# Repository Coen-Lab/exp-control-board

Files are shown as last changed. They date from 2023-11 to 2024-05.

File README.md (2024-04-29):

# Experimental Control Board (ECB)
This repository houses the electronics, firmware, and enclosure design for the experimental control board. This board was designed by [Max Hunter](https://maxhunter.me/), to the specifications of Philip Coen. It  is designed both with features that are universally applicable to experimental neuroscience rigs, as well as some features which may not (but may) be useful outside the Coen Lab. In particular, the assembled board can be purchased at a comparable price to a _single component_ from a commercial supplier (e.g. this [current driver](https://www.thorlabs.com/thorproduct.cfm?partnumber=LEDD1B) or this [adjustable photodiode](https://www.thorlabs.com/thorproduct.cfm?partnumber=PDA8A2)). For most applications, this board can fully replace these components (in the enclosure of the current driver, it can replace 3 of them), amongst others.

<p align="center">

</p>

If purchased directly from Max, the Version 3 board includes:
- 24V, 220W power supply
- Photodiode (2-pin)
- Temperature sensor (3-pin)
- Enclosure (Pink in above images)
- ECB Version 3 with the following features
	- Temperature-controlled PID Peltier cooler output with overheat protection
	- Two fixed 12V, 3A power rails for auxiliary devices, with switchable on/off outputs
	- Four variable 3-24V, 3A power rails for auxiliary devices, with switchable on/off outputs
	- Three adjustable 0-1A continuous current drivers for LEDs or similar devices
	- Photosensor with variable sensitivity trigger (5V TTL digital output)
	- Two DRV104 valve controllers, 12V output
	- One Arduino Nano V3, used to control Peltier output and random ‘flipper’ output, with 6 spare IO for future expansion

For useage instructions, please see:

[Version 3 documentation](Version3/README.md)

To purchase pre-assembled units, including photodiode etc. mentioned above, for ~£450 (at time of writing), please contact [Max Hunter](https://maxhunter.me/). 

All details are open source, and you can alternatively print your own boards: there is a folder of Gerbers and pick 'n place files for each version. However, please be aware that stock levels may necessitate equivalent-part subsitutions, so if you aren't familiar with ordering your own PCBs (e.g. you have no idea what Gerbers and pick 'n place files are), then we _strongly_ recommend you order pre-assembled units. Max may also be able to make minor design changes (for a design fee) if there are particular elements you would like added or removed.

&nbsp;
&nbsp;
This work is licensed under a
[Creative Commons Attribution-NonCommercial-ShareAlike 4.0 International License][cc-by-nc-sa].

[][cc-by-nc-sa]

[cc-by-nc-sa]: http://creativecommons.org/licenses/by-nc-sa/4.0/
[cc-by-nc-sa-image]: https://licensebuttons.net/l/by-nc-sa/4.0/88x31.png
[cc-by-nc-sa-shield]: https://img.shields.io/badge/License-CC%20BY--NC--SA%204.0-lightgrey.svg

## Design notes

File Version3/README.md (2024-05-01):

## ECB Version 3 guide and usage instructions
<p align="center">

</p>

_Above_: Version 3 board CAD file (left) with both top and bottom of enclosure (centre) or just the bottom of the enclosure (right)

Thanks for purchasing (or considering) the ECB Version 3! This guide should act as a basic how-to to get started. If you have any questions/issues please post them on this github so that the entire community can benefit from the answers.

A purchasable Bill of Materials, all source code for the Arduino, a 3D-printable enclosure, and electronics design files can be found in this repository.

The board comes with a one-year warranty against manufacturing defects.

If you have any further questions or have any problems, please leave an issue on this GitHub repository.

## General notes
If purchased directly from Max, you have received:

- 24V, 220W power supply
- Photodiode (2-pin)
- Temperature sensor (3-pin)
- ECB Version 3 with the following features
    - Temperature-controlled PID Peltier cooler output with overheat protection
    - Two fixed 12V, 3A power rails for auxiliary devices, with switchable on/off outputs
    - Four variable 3-24V, 3A power rails for auxiliary devices, with switchable on/off outputs
    - Three adjustable 0-1A continuous current drivers for LEDs or similar devices
    - Photosensor with variable sensitivity trigger (5V TTL digital output)
    - Two DRV104 valve controllers, 12V output
    - One Arduino Nano V3, used to control Peltier output and random ‘flipper’ output, with 6 spare IO for future expansion

Please take the following precautions when handling the board.

* **At no point should you “hot-plug” / screw or unscrew anything into the board when it is powered on. The rapid transients caused by the making/breaking of contacts when screwing a cable in can damage the board as well as any attached components.**
* Do not overload or short-circuit any of the power rails.
* Please pay attention to the total maximum power rating of 220W, which is possible to exceed if fully loading all voltage rails.
* When handling or touching any components on the board, you should ground yourself with an ESD bracelet (£4 on Amazon) or by touching any grounded surface to dissipate electrostatic charge. Humans can accumulate several thousand volts of static charge which will dissipate through the board: several of the components on the board are very sensitive to ESD. When screwing in any of the terminals, take the same precaution, or use an insulated screwdriver so your skin does not make contact with the screw of the terminal.

## Installation/operation instructions

### General notes on screw terminals
All the external connections to the board are made using screw terminals. These accept a wide variety of wire sizes. You should strip 5mm off the wire, then unscrew the terminal until the jaws fully open, insert the wire, and hand-tighten. The screw should clamp down on the conductor (not the insulation) and no conductor should be visible out the end of the connector.

For low-power devices with small cable sizes it is acceptable to insert several wires into a single terminal, as long as they are all sufficiently stripped so that they are making good contact with the terminal.

### Enclosure
Four self-tapping screws can be inserted into the four corners of the enclosure in the pre-drilled holes to mount onto any suitable surface. The board can be installed in any orientation but preferably should be kept away from direct sunlight and heat sources.

### Power in


The board comes with a switchmode 24V, 220W power supply. You should sum up all the power ratings of the various attached devices (including Peltier cooler) and make sure they do not exceed 220W.

Once in the correct position, the insulation on the power connector should be cut off and the ends stripped to 5mm. Slightly twist the copper to make sure no strands splay off, then insert BLACK into ⏚ and RED into +24.

### Power out


There are 6 power rails for auxiliary devices on this board. All of them share the same 3A current rating.

RAIL 1: 12V fixed

RAIL 2: 12V fixed

RAIL 3: Variable 3-23V

RAIL 4: Variable 3-23V

RAIL 5: Variable 3-23V

RAIL 6: Variable 3-23V

RAIL 3-6 are adjustable by turning the potentiometers (blue cuboids) next to the relevant rails with a small insulated flat screwdriver, whilst metering the output voltage with the serial logger on the Arduino, or a multimeter. Care should be taken to make sure the screwdriver does not slip and you do not touch any other components while metering, especially if using a multimeter.

All rails have a GATE input. Leaving this pin disconnected, or connecting this to a voltage below approximately 1.3 V, turns the regulator on, and pulling this pin above 1.3 V (up to a maximum of 25 V) shuts the regulator down. This is a useful feature if you wish to use an Arduino pin (or other logic pin) to switch power to an external component. (Note that there are output capacitors on the voltage rails so the power will not switch off instantly)

### Peltier


This board is tested and designed to work with the following 24V, 60W Peltier cooling module: [https://uk.rs-online.com/web/p/heat-pumps/7777079](https://uk.rs-online.com/web/p/heat-pumps/7777079). Other modules may work, as long as they are 24V and do not exceed 8A.

Insert BLACK into ⏚ and RED into PELT.

Connect overheat switch to any terminal marked ⏚ and OHT (polarity does not matter). This is a NC (normally closed) design which opens if the Peltier overheats - if your Peltier unit does not have an overheat sensor you should either modify the Arduino code or put a small bit of wire between OHT and ⏚ to bypass it.

The temperature sensor (mandatory for Peltier cooling) should be plugged into T SENSOR. Red into +5, yellow into D (data), black into ⏚. It should be positioned close to/underneath the desired position to be kept at a constant temperature.

The two fans (if available) should be plugged into any +12V rail.

The code for the Peltier follows a PID loop with a frequency of approximately 800KHz. It is roughly tuned for The Coen Lab’s original experimental box and so the P, I, D constants may need adjusting if the temperature proves to oscillate or under/overshoot in a new environment or with a different Peltier.

### Photodiode


This is a completely separate module from the rest of the board, designed as an adjustable photodiode trigger at a user-settable light threshold - originally designed to be placed next to a square on a screen to synchronise it with experimental data. This turns a variable light level into a digital 5V TTL logic output. There is a Schmitt trigger to remove hysteresis. The included photodiode (optional) should be plugged with the RED wire into S- and the BLUE wire into S+. The photodiode should be placed in the desired position and the potentiometer adjusted for the desired sensitivity.

The output between OUT and ⏚ is the 5V TTL out. The output between RAW and ⏚ is designed as an ‘analogue backup’ in case the sensitivity is slightly wrong - it is an analogue voltage (controlled by the SENSITIVITY  knob) before the Schmitt comparator where 2.5V is approximately the midpoint threshold.

### Valve drivers


These are 2 completely independent valve drivers. They take 5V TTL logic in (between IN and ⏚) and connect to a valve. The specs are fixed and as follows:

This was designed for the following valve:

225P011-21 ([https://www.nresearch.com/products/valves/pinch-1xnc.html](https://www.nresearch.com/products/valves/pinch-1xnc.html))

When the logic level input goes above approximately 2.2V (maximum 5.5V) the output briefly rises to 12V for 100ms, then continues to pulse between 0V and 12V at a 33% duty cycle until the input voltage drops beneath approximately 1.2V. This keeps the valve open without burning out the solenoid.

### Constant current drivers
\
\

There are 3 constant-current drivers on this board. They are adjustable in 3 fixed steps: 333mA, 667mA, 1000mA, by adding or removing jumpers on the board as shown.

They can also be controlled with the CTL pin for the relevant output as follows:

0-2.5V: scales linearly between 0A and the maximum set current (i.e. if the jumpers are set to 1A, setting the CTL pin at 1.25V will output a target current of 500mA).

2.5-5V: fully ON.

This can be used either as analogue control from 0-2.5V, or as a digital on/off switch by modulating the input voltage between 0 and 5V.

There is an internal pull-up resistor, so leaving this pin floating is the same as pulling it up to +5V (ie "on").

### Arduino I/O
\

This is a breakout board for the included Arduino Nano v3. 

The implemented features in the provided firmware are:

A ‘flipper’ random I/O which randomly flips between HIGH and LOW approximately every 100ms. This is turned on and off by setting FE (flipper enable) to HIGH or LOW.

An OHT overheat sensor for the Peltier (described in the Peltier section above)

Two ⏚ ground terminals and a 5V logic output. This 5V output is a logic reference only and not to be used for power. Drawing more than 50mA of current through it will result in permanent damage to the board. If there is any chance of it shorting to ground (or any other voltage), a 200 ohm resistor in series with it is strongly recommended.

The other outputs match the Arduino pinout and are reserved for future expansion.

Plugging the board into a computer is optional and only needed if you wish to log temperature/rail voltages etc, or update the firmware.

The firmware is available on GitHub and can be modified and uploaded using the connector on the Arduino. Plugging in the USB-C connector and opening up the serial logger on the Arduino app (or a MATLAB/Python program) will print rail voltages and temperature. You can then use the Arduino app to reflash any firmware changes.

## Manufacturing instructions

### Board

A service like JLCPCB can be used with the included Gerber and pick&place files to manufacture and assemble the board.

### Enclosure


Pip Coen has designed a 3D-printable enclosure which can be found in this repository.

The enclosure is designed to take 8 regular M4 nuts and M4 bolts.

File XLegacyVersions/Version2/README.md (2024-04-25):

## PipCB v2 assembly and usage instructions

### Max Hunter, March 2024

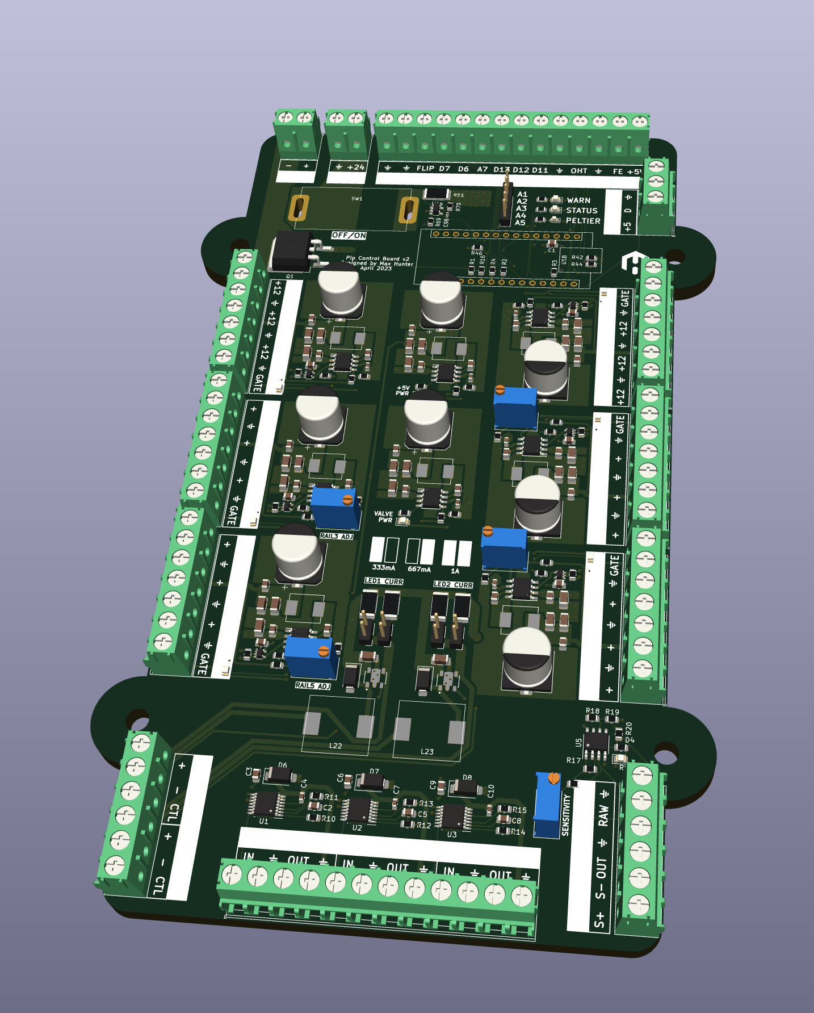
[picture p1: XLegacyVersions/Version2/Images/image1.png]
Overview


Thanks for purchasing a PipCB! This guide should act as a basic how-to to get started.

A purchasable Bill of Materials, all source code for the Arduino, and electronics design files can be found in this repository.

The board comes with a one-year warranty against manufacturing defects.

If you have any further questions or have any problems, please leave an issue on this GitHub repository.

## General notes

This board was designed by [Max Hunter](https://maxhunter.me/), to the specifications of Philip Coen. It  is designed both with features that are universally applicable to experimental neuroscience rigs, as well as some features which may not (but may) be useful outside the Coen Lab. In particular, the entire board costs less than the commercial equivalent of some single features (e.g. constant current delivery, or a thresholded, adjustable photodiode circuit).

The board as sold comprises:

- 24V, 220W power supply
- Photodiode (2-pin)
- Temperature sensor (3-pin)
- Enclosure
- ECB Version 2 with the following features
    - Temperature-controlled PID Peltier cooler output with overheat protection
    - Two fixed 12V, 3A power rails for auxiliary devices, with switchable on/off outputs
    - Four variable 3-24V, 3A power rails for auxiliary devices, with switchable on/off outputs
    - Two adjustable 0-1A continuous current drivers for LEDs or similar devices
    - Photosensor with variable sensitivity trigger (5V TTL digital output)
    - Three DRV104 valve controllers, 12V output
    - One Arduino Nano V3, used to control Peltier output and random ‘flipper’ output, with 6 spare IO for future expansion

Please take the following precautions when handling the board.

* **At no point should you “hot-plug” / screw or unscrew anything into the board when it is powered on. The rapid transients caused by the making/breaking of contacts when screwing a cable in can damage the board as well as any attached components.**
* Do not overload or short-circuit any of the power rails.
* Please pay attention to the total maximum current rating of 220W, which is possible to exceed if fully loading all voltage rails.
* When handling or touching any components on the board, you should ground yourself with an ESD bracelet (£4 on Amazon) or by touching any grounded surface to dissipate electrostatic charge. Humans can accumulate several thousand volts of static charge which will dissipate through the board: several of the components on the board are very sensitive to ESD. When screwing in any of the terminals, take the same precaution, or use an insulated screwdriver so your skin does not make contact with the screw of the terminal.

## Installation/operation instructions

### General notes on screw terminals

All the external connections to the board are made using screw terminals. These accept a wide variety of wire sizes. You should strip 5mm off the wire, then unscrew the terminal until the jaws fully open, insert the wire, and hand-tighten. The screw should clamp down on the conductor (not the insulation) and no conductor should be visible out the end of the connector.

For low-power devices with small cable sizes it is acceptable to insert several wires into a single terminal, as long as they are all sufficiently stripped so that they are making good contact with the terminal.

### Case

Four self-tapping screws can be inserted into the four corners of the case in the pre-drilled holes to mount onto any suitable surface. The board can be installed in any orientation but preferably should be kept away from direct sunlight and heat sources.

### Power in

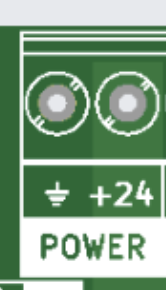
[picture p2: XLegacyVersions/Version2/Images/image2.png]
Power in Power input


The board comes with a switchmode 24V, 220W power supply. You should sum up all the current ratings of the various attached devices (including Peltier cooler) and make sure they do not exceed 220W.

Once in the correct position, the insulation on the power connector should be cut off and the ends stripped to 5mm. Slightly twist the copper to make sure no strands splay off, then insert BLACK into ⏚ and RED into +24.

### Power out

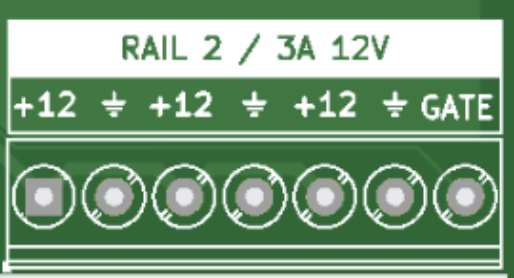
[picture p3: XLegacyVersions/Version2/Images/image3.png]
Power outputs


There are 6 power rails for auxiliary devices on this board. All of them share the same 3A current rating.

RAIL 1: 12V fixed

RAIL 2: 12V fixed

RAIL 3: Variable 3-23V

RAIL 4: Variable 3-23V

RAIL 5: Variable 3-23V

RAIL 6: Variable 3-23V

RAIL 3-6 are adjustable by turning the potentiometers next to the relevant rails with a small insulated flat screwdriver, whilst metering the output voltage with the serial logger on the Arduino, or a multimeter. Care should be taken to make sure the screwdriver does not slip and you do not touch any other components while metering, especially if using a multimeter.

All rails have a GATE input. Leaving this pin disconnected, or connecting this to a voltage below approximately 1.3 V, turns the regulator on, and pulling this pin above 1.3 V (up to a maximum of 25 V) shuts the regulator down. This is a useful feature if you wish to use an Arduino pin (or other logic pin) to switch power to an external component. (Note that there are output capacitors on the voltage rails so the power will not switch off instantly)

### Peltier

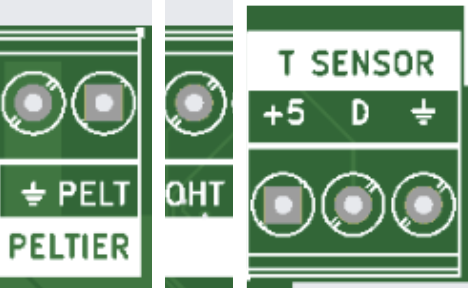
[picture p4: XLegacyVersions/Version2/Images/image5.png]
Peltier Peltier connectors


This board is tested and designed to work with the following 24V, 60W Peltier cooling module: [https://uk.rs-online.com/web/p/heat-pumps/7777079](https://uk.rs-online.com/web/p/heat-pumps/7777079). Other modules may work, as long as they are 24V and do not exceed 8A.

Insert BLACK into ⏚ and RED into PELT.

Connect overheat switch to any terminal marked ⏚ and OHT (polarity doesn’t matter). This is a NC (normally closed) design which opens if the Peltier overheats - if your Peltier unit does not have an overheat sensor you should either modify the Arduino code or put a small bit of wire between OHT and ⏚ to bypass it.

The temperature sensor (mandatory for Peltier cooling) should be plugged into T SENSOR. Red into +5, yellow into D (data), black into ⏚. It should be positioned close to/underneath the desired position to be kept at a constant temperature.

The two fans (if available) should be plugged into any +12V rail.

The code for the Peltier follows a PID loop with a frequency of approximately 800KHz. It is roughly tuned for Pip’s original experimental box and so the P, I, D constants may need adjusting if the temperature proves to oscillate or under/overshoot in a new environment or with a different Peltier.

### Photodiode

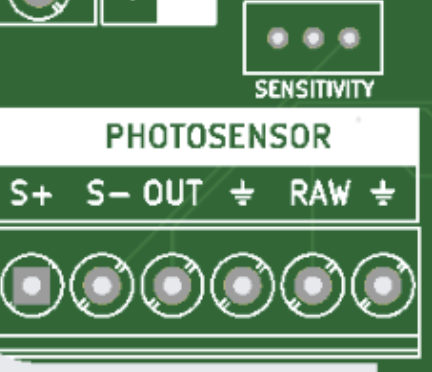
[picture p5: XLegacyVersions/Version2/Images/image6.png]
Photodiode Photodiode connectors


This is a completely separate module from the rest of the board, designed as an adjustable photodiode trigger at a user-settable light threshold - originally designed to be placed next to a square on a screen to synchronise it with experimental data. This turns a variable light level into a digital 5V TTL logic output. There is a Schmitt trigger to remove hysteresis. The included photodiode (optional) should be plugged with the RED wire into S- and the BLUE wire into S+. The photodiode should be placed in the desired position and the potentiometer adjusted for the desired sensitivity.

The output between OUT and ⏚ is the 5V TTL out. The output between RAW and ⏚ is designed as an ‘analogue backup’ in case the sensitivity is slightly wrong - it is an analogue voltage (controlled by the SENSITIVITY  knob) before the Schmitt comparator where 2.5V is approximately the midpoint threshold.

### Valve drivers

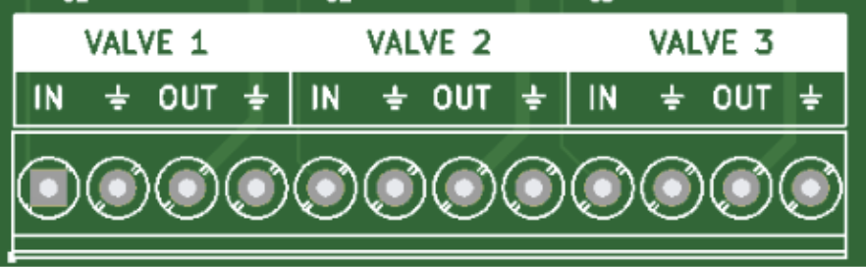
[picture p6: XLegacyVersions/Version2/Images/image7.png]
Valve drivers


These are 3 completely independent valve drivers. They take 5V TTL logic in (between IN and ⏚) and connect to a valve. The specs are fixed and as follows:

This was designed for the following valve:

225P011-21 ([https://www.nresearch.com/products/valves/pinch-1xnc.html](https://www.nresearch.com/products/valves/pinch-1xnc.html))

When the logic level input goes above approximately 2.2V (maximum 5.5V) the output briefly rises to 12V for 100ms, then continues to pulse between 0V and 12V at a 33% duty cycle until the input voltage drops beneath approximately 1.2V. This keeps the valve open without burning out the solenoid.

### Constant current drivers

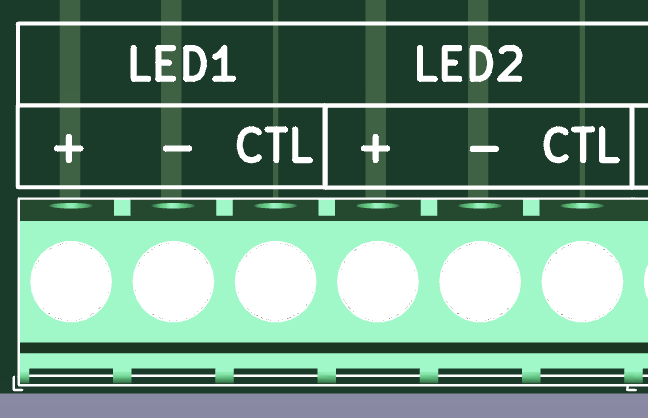
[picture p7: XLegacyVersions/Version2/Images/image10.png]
Constant current drivers

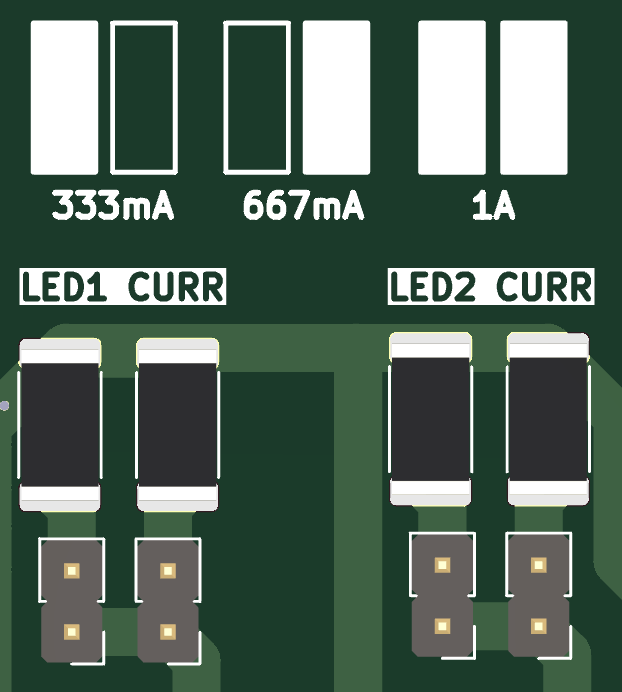
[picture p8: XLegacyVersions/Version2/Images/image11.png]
Jumpers


There are 2 constant-current drivers on this board. They are adjustable in 3 fixed steps: 333mA, 667mA, 1000mA, by adding or removing jumpers on the board as shown.

They can also be controlled with the CTL pin for the relevant output as follows:

0-2.5V: scales linearly between 0A and the maximum set current (i.e. if the jumpers are set to 1A, setting the CTL pin at 1.25V will output a target current of 500mA).

2.5-5V: fully ON.

This can be used either as analogue control from 0-2.5V, or as a digital on/off switch by modulating the input voltage between 0 and 5V.

There is an internal pull-up resistor, so leaving this pin floating is the same as pulling it up to +5V (ie "on").

### Arduino I/O

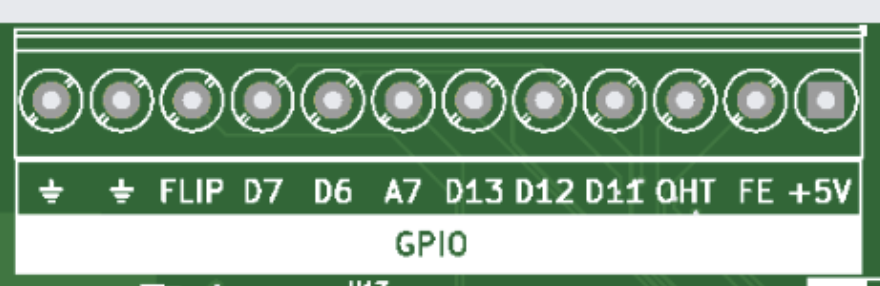
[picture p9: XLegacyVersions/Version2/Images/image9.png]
Arduino I/O


This is a breakout board for the included Arduino Nano v3. 

The currently implemented features are:

A ‘flipper’ random I/O which randomly flips between HIGH and LOW approximately every 100ms. This is turned on and off by setting FE (flipper enable) to HIGH or LOW.

An OHT overheat sensor for the Peltier (described in the Peltier section above)

Two ⏚ ground terminals and a 5V logic output. This 5V output is a logic reference only and not to be used for power. Drawing more than 50mA of current through it will result in permanent damage to the board. If there is any chance of it shorting to ground (or any other voltage), a 200 ohm resistor in series with it is strongly recommended.

The other outputs match the Arduino pinout and are reserved for future expansion.

Plugging the board into a computer is optional and only needed if you wish to log temperature/rail voltages etc, or update the firmware.

The firmware is available on GitHub and can be modified and uploaded using the connector on the Arduino. Plugging in the USB-C connector and opening up the serial logger on the Arduino app (or a MATLAB/Python program) will print rail voltages and temperature. You can then use the Arduino app to reflash any firmware changes.

## Manufacturing instructions

### Board

A service like JLCPCB can be used with the included Gerber and pick&place files to manufacture and assemble the board.

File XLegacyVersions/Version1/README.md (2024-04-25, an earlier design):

## PipCB v1 assembly and usage instructions

### Max Hunter, Jan 2023

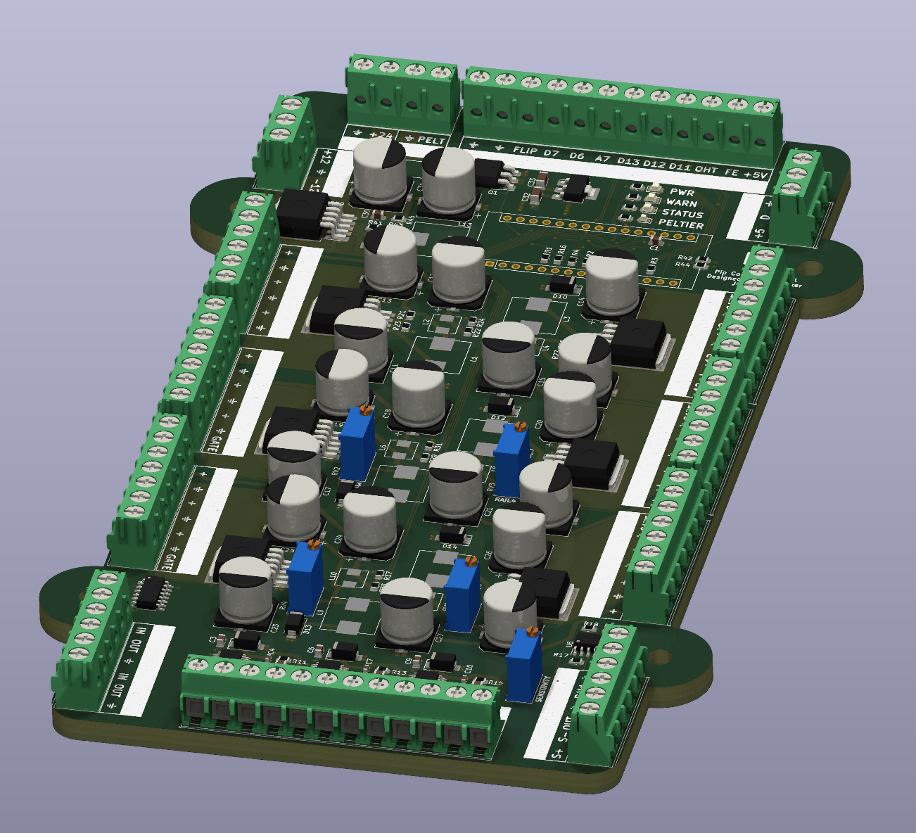
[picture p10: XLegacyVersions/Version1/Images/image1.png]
Overview


Thanks for purchasing a PipCB! This guide should act as a basic how-to to get started.

A purchasable Bill of Materials, all source code for the Arduino, electronics design files, and a 3D-printable case to replace the original grey one can be found in this repository.

The board comes with a one-year warranty against manufacturing defects.

If you have any further questions or have any problems, please leave an issue on this GitHub repository.

## General notes

This board was designed by [Max Hunter](https://maxhunter.me/), to the specifications of Philip Coen. It  is designed both with features that are universally applicable to experimental neuroscience rigs, as well as some features which may not (but may) be useful outside the Coen Lab. In particular, the entire board costs less than the commercial equivalent of some single features.

The board as sold comprises:

* 24V, 220W power supply
* Photodiode (2-pin)
* Temperature sensor (3-pin)
* Enclosure
* PipCB v1, with the following features
    * Temperature-controlled PID Peltier cooler output with overheat protection
    * Two fixed 12V, 3A(max) 2A(continuous) power rails for auxiliary devices, one with switchable on/off output
    * Four variable 3-23V, 3A(max) 2A(continuous) power rails for auxiliary devices, all with switchable on/off outputs
    * One 1A ±12V, zero-centred power supply for Thorlabs photodiode
    * Photosensor with variable sensitivity trigger (5V TTL digital output)
    * Three DRV104 valve controllers, 12V output
    * Two logic inverters (5V TTL logic I/O)
    * One Arduino Nano V3, used to control Peltier output and random ‘flipper’ output, with 6 spare IO for future expansion

Please take the following precautions when handling the board.

* **At no point should you “hot-plug” / screw or unscrew anything into the board when it is powered on. The rapid transients caused by the making/breaking of contacts when screwing a cable in can damage the board as well as any attached components.**
* Do not overload or short-circuit any of the power rails. In particular, the +5V reference logic output is only rated for 50mA and is not for powering any other device! The other power rails should not be continuously loaded with more than 2A.
* Please pay attention to the total maximum current rating of 220W, which is possible to exceed if fully loading all voltage rails.
* When handling or touching any components on the board, you should ground yourself with an ESD bracelet (£4 on Amazon) or by touching any grounded surface to dissipate electrostatic charge. Humans can accumulate several thousand volts of static charge which will dissipate through the board: several of the components on the board are very sensitive to ESD. When screwing in any of the terminals, take the same precaution, or use an insulated screwdriver so your skin does not make contact with the screw of the terminal.

## Installation/operation instructions

### General notes on screw terminals

All the external connections to the board are made using screw terminals. These accept a wide variety of wire sizes. You should strip 5mm off the wire, then unscrew the terminal until the jaws fully open, insert the wire, and hand-tighten. The screw should clamp down on the conductor (not the insulation) and no conductor should be visible out the end of the connector.

For low-power devices with small cable sizes it is acceptable to insert several wires into a single terminal, as long as they are all sufficiently stripped so that they are making good contact with the terminal.

### Case

Four self-tapping screws can be inserted into the four corners of the case in the pre-drilled holes to mount onto any suitable surface. The board can be installed in any orientation but preferably should be kept away from direct sunlight and heat sources.

### Power in

Power in Power input

The board comes with a switchmode 24V, 220W power supply. A self-resetting thermal polyfuse will protect against severe sudden overload, but permanent damage to the power supply is still possible if the wattage rating is exceeded. You should sum up all the current ratings of the various attached devices (including Peltier cooler) and make sure they do not exceed 220W.

Once in the correct position, the insulation on the power connector should be cut off and the ends stripped to 5mm. Slightly twist the copper to make sure no strands splay off, then insert BLACK into ⏚ and RED into +24.

### Power out

Power outputs

There are 6 power rails for auxiliary devices on this board. All of them share the same 3A (maximum), 2A (continuous) current rating.

RAIL 1: 12V fixed*

RAIL 2: 12V fixed

RAIL 3: Variable 3-23V

RAIL 4: Variable 3-23V

RAIL 5: Variable 3-23V

RAIL 6: Variable 3-23V

RAIL 3-6 are adjustable by turning the potentiometers next to the relevant rails with a small insulated flat screwdriver, whilst metering the output voltage with the serial logger on the Arduino, or a multimeter. Care should be taken to make sure the screwdriver does not slip and you do not touch any other components while metering, especially if using a multimeter.

**NOTE:** RAIL 1 powers the internal 5V regulator for the Arduino and other 5V peripherals, as well as the valve drivers and +12V rail of the Thorlabs photodiode power supply. For this reason, it does not have a switchable power-off GATE on it and it should only be used for low-power devices that will not dirty the power supply. It is recommended to use RAILS 2-6 first and use RAIL 1 only when the others are full up.

RAIL 2-6 have a GATE input. Leaving this pin disconnected, or connecting this to a voltage below approximately 1.3 V, turns the regulator on, and pulling this pin above 1.3 V (up to a maximum of 25 V) shuts the regulator down. This is a useful feature if you wish to use an Arduino pin (or other logic pin) to switch power to an external component. (Note that there are output capacitors on the voltage rails so the power will not switch off instantly)

### Thorlabs photodiode power

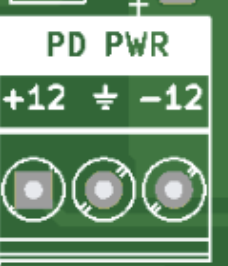
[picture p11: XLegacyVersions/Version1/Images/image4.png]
Photodiode power


This is a 1A ±12V, zero-centred power supply designed for Thorlabs photodiodes. The +12V output is shared with RAIL 1.

### Peltier

Peltier Peltier connectors

This board is tested and designed to work with the following 24V, 60W Peltier cooling module: [https://uk.rs-online.com/web/p/heat-pumps/7777079](https://uk.rs-online.com/web/p/heat-pumps/7777079). Other modules may work, as long as they are 24V and do not exceed 8A.

Insert BLACK into ⏚ and RED into PELT.

Connect overheat switch to any terminal marked ⏚ and OHT (polarity doesn’t matter). This is a NC (normally closed) design which opens if the Peltier overheats - if your Peltier unit does not have an overheat sensor you should either modify the Arduino code or put a small bit of wire between OHT and ⏚ to bypass it.

The temperature sensor (mandatory for Peltier cooling) should be plugged into T SENSOR. Red into +5, yellow into D (data), black into ⏚. It should be positioned close to/underneath the desired position to be kept at a constant temperature.

The two fans (if available) should be plugged into any +12V rail.

The code for the Peltier follows a PID loop with a frequency of approximately 800KHz. It is roughly tuned for Pip’s original experimental box and so the P, I, D constants may need adjusting if the temperature proves to oscillate or under/overshoot in a new environment or with a different Peltier.

### Photodiode

Photodiode Photodiode connectors

This is a completely separate module from the rest of the board, designed as an adjustable photodiode trigger at a user-settable light threshold - originally designed to be placed next to a square on a screen to synchronise it with experimental data. This turns a variable light level into a digital 5V TTL logic output. There is a Schmitt trigger to remove hysteresis. The included photodiode (optional) should be plugged with the RED wire into S- and the BLUE wire into S+. The photodiode should be placed in the desired position and the potentiometer adjusted for the desired sensitivity.

The output between OUT and ⏚ is the 5V TTL out. The output between RAW and ⏚ is designed as an ‘analogue backup’ in case the sensitivity is slightly wrong - it is an analogue voltage (controlled by the SENSITIVITY  knob) before the Schmitt comparator where 2.5V is approximately the midpoint threshold.

### Valve drivers

Valve drivers

These are 3 completely independent valve drivers (powered by RAIL 1). They take 5V TTL logic in (between IN and ⏚) and connect to a valve. The specs are fixed and as follows:

This was designed for the following valve:

225P011-21 ([https://www.nresearch.com/products/valves/pinch-1xnc.html](https://www.nresearch.com/products/valves/pinch-1xnc.html))

When the logic level input goes above approximately 2.2V (maximum 5.5V) the output briefly rises to 12V for 100ms, then continues to pulse between 0V and 12V at a 33% duty cycle until the input voltage drops beneath approximately 1.2V. This keeps the valve open without burning out the solenoid.

### Inverters

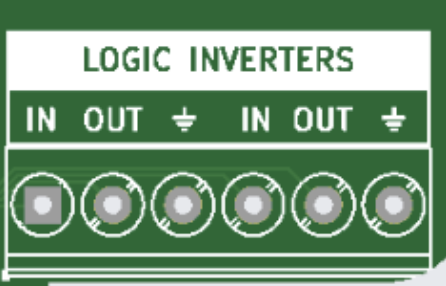
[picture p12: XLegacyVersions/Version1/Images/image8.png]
Inverters


This is two channels of a 74HC14 5V TTL logic inverter and is completely separate from the rest of the board. A 5V signal between IN and ⏚ will produce 0V between OUT and ⏚. A 0V signal between IN and ⏚ will produce 5V between OUT and ⏚.

### Arduino I/O

Arduino I/O

This is a breakout board for the included Arduino Nano v3. 

The currently implemented features are:

A ‘flipper’ random I/O which randomly flips between HIGH and LOW approximately every 100ms. This is turned on and off by setting FE (flipper enable) to HIGH or LOW.

An OHT overheat sensor for the Peltier (described in the Peltier section above)

Two ⏚ ground terminals and a 5V logic output. This 5V output is a logic reference only and not to be used for power. Drawing more than 50mA of current through it will result in permanent damage to the board. If there is any chance of it shorting to ground (or any other voltage), a 200 ohm resistor in series with it is strongly recommended.

The other outputs match the Arduino pinout and are reserved for future expansion.

Plugging the board into a computer is optional and only needed if you wish to log temperature/rail voltages etc, or update the firmware.

The firmware is available on GitHub and can be modified and uploaded using the connector on the Arduino. Plugging in the USB-C connector and opening up the serial logger on the Arduino app (or a MATLAB/Python program) will print rail voltages and temperature. You can then use the Arduino app to reflash any firmware changes.

## Manufacturing instructions

### Board

A service like JLCPCB can be used with the included Gerber and pick&place files to manufacture and assemble the board.

### Case

Pip Coen has designed a 3D-printable case which can be found in this repository.

The base is designed to take 5, [M4 threaded inserts](https://uk.rs-online.com/web/p/threaded-inserts/0278556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). Also, it's designed to accommodate [these](https://cpc.farnell.com/pro-signal/psg91738/usb-c-male-90-degree-female-adapter/dp/CS33856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) right-angled USB-C adaptors to make it easier to plug in the Arduino.

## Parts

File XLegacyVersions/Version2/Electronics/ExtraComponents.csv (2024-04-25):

Qty | MOQ | Item | Price | Link | Qty total | Price
1 | 1 | DS18B20 | 3.12 | https://www.mouser.co.uk/ProductDetail/Maxim-Integrated/DS18B20+TR?qs=7H2Jq%252ByxpJKpIDCbiq4lfg%3D%3D | 25 | 78
1 | 1 | PSU | 62.88 | https://www.mouser.co.uk/ProductDetail/Cincon/TRH220A240-1538E12-VI?qs=Znm5pLBrcALJXoCr1%2FrOzQ%3D%3D | 25 | 1572
1 | 1 | Photosensor |  | https://uk.rs-online.com/web/p/photodiodes/6548154/ | 25
1 | 1 | Power switch | 5.34 | https://uk.rs-online.com/web/p/toggle-switches/2066972 | 25 | 48.25
1 | 1 | 10M trim | 1.93 | https://www.mouser.co.uk/ProductDetail/Bourns/3296W-1-505LF | 25 | 48.25
3 | 10 | 2-way terminal block |  |  | 50 | 29.5
1 | 10 | 3-way terminal block | 0.59 | https://uk.rs-online.com/web/p/pcb-terminal-blocks/8970812 | 50 | 29.5
2 | 5 | 6-way terminal block | 1.224 | https://uk.rs-online.com/web/p/pcb-terminal-blocks/8970828 | 75 | 91.8
6 | 5 | 7-way terminal block | 1.45 | https://uk.rs-online.com/web/p/pcb-terminal-blocks/8970821 | 125 | 181.25
2 | 5 | 12-way terminal block | 1.612 | https://uk.rs-online.com/web/p/pcb-terminal-blocks/8970840 | 50 | 80.6
1 |  | Arduino |  |  | 25 | 0
4 |  | 2.54mm jumper |  |  | 0 | 0
2 |  | 15-way 2.54mm header

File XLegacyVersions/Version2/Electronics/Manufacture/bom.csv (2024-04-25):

Designator | Footprint | Quantity | Value | LCSC Part #
A1 | Arduino_Nano | 1 | Arduino_Nano_v3.x
C1, C11, C12, C13, C14, C15, C16, C38, C45, C53, C61, C69, C77, C85, C93 | 0805 | 15 | 100n | C28233
C10, C4, C7 | 0603 | 3 | 470p | C1620
C100, C101, C102, C103, C104, C105, C106, C99 | CP_Elec_10x10 | 8 | 100u | C371283
C2, C5, C8 | 0805 | 3 | 150n | C376934
C3, C6, C9 | 0805 | 3 | 1u | C28323
C32, C33, C37, C39, C40, C42, C46, C47, C50, C54, C55, C58, C62, C63, C66, C70, C71, C74, C78, C79, C82, C86, C87, C90, C94, C95 | 1206 | 26 | 10u | C13585
C34, C36, C43, C44, C51, C52, C59, C60, C67, C68, C75, C76, C83, C84, C91, C92 | 0805 | 16 | 220n | C5378
C35, C49, C57, C65, C73, C81, C89, C97 | 0603 | 8 | 1u | C15849
C98 | 0402 | 1 | 10p | C32949
D1, D10, D11, D12, D13, D14, D15, D9 | 0805 | 8 | PG | C2297
D16, D17, D6, D7, D8 | D_SMA | 5 | SS34 | C8678
D2 | 0805 | 1 | RED | C84256
D3 | 0805 | 1 | YELLOW | C2296
D4 | 0805 | 1 | GREEN | C2297
D5 | 0603 | 1 | BLUE | C72041
J1 | TerminalBlock_Phoenix_PT-1,5-2-5.0-H_1x02_P5.00mm_Horizontal | 1 | PWR
J10 | TerminalBlock_Phoenix_PT-1,5-3-5.0-H_1x03_P5.00mm_Horizontal | 1 | TEMP_SENSOR
J11 | TerminalBlock_Phoenix_PT-1,5-12-5.0-H_1x12_P5.00mm_Horizontal | 1 | VALVES
J12 | TerminalBlock_Phoenix_PT-1,5-6-5.0-H_1x06_P5.00mm_Horizontal | 1 | PHOTOSENSOR
J13 | TerminalBlock_Phoenix_PT-1,5-2-5.0-H_1x02_P5.00mm_Horizontal | 1 | PELTIER
J14 | PinHeader_1x05_P2.54mm_Vertical | 1 | GPIO_INT
J2 | TerminalBlock_Phoenix_PT-1,5-7-5.0-H_1x07_P5.00mm_Horizontal | 1 | RAIL1
J3 | TerminalBlock_Phoenix_PT-1,5-7-5.0-H_1x07_P5.00mm_Horizontal | 1 | RAIL2
J4 | TerminalBlock_Phoenix_PT-1,5-7-5.0-H_1x07_P5.00mm_Horizontal | 1 | RAIL3
J5 | TerminalBlock_Phoenix_PT-1,5-7-5.0-H_1x07_P5.00mm_Horizontal | 1 | RAIL4
J6 | TerminalBlock_Phoenix_PT-1,5-7-5.0-H_1x07_P5.00mm_Horizontal | 1 | RAIL5
J7 | TerminalBlock_Phoenix_PT-1,5-7-5.0-H_1x07_P5.00mm_Horizontal | 1 | RAIL6
J8 | TerminalBlock_Phoenix_PT-1,5-14-5.0-H_1x14_P5.00mm_Horizontal | 1 | ARDUINO
J9 | TerminalBlock_Phoenix_PT-1,5-6-5.0-H_1x06_P5.00mm_Horizontal | 1 | LED
JP1, JP2, JP3, JP4 | PinHeader_1x02_P2.54mm_Vertical | 4 | JUMP | C5305
L14, L15, L16, L17, L18, L19, L20, L21 | L_Cenker_CKST0603 | 8 | 15uH 4A | C3002651
L22, L23 | L_SMMS1360 | 2 | 100uH | C149534
Q1 | TO-263-2 | 1 | LNE08R085 | C483709
R1, R54, R56, R58, R60, R70 | 0805 | 6 | 4.7k | C17673
R10, R12, R14 | 0805 | 3 | 120k | C17436
R11, R13, R15 | 0805 | 3 | 200k | C17539
R16, R2, R21, R22, R23, R24, R25, R26, R27, R3, R4, R5, R6, R7 | 0805 | 14 | 220R | C17557
R17, R46, R47 | 0805 | 3 | 10K | C17414
R18, R19 | 0805 | 2 | 30k | C17621
R20 | 0805 | 1 | 150k | C17470
R28, R29, R30, R31, R32, R33, R42 | 0805 | 7 | 47k 1% | C17713
R44 | 0805 | 1 | 8.87k 1% | C37551
R48, R50, R53, R55, R57, R59, R61, R63 | 0805 | 8 | 100k 1% | C149504
R49, R52, R62 | 0805 | 3 | 9.09k 1% | C408923
R51 | 2512 | 1 | 0.005R | C5121085
R64 | 0805 | 1 | 24.9k 1% | C234872
R65, R66 | 2512 | 2 | 0.15R | C2924565
R67, R68 | 2512 | 2 | 0.3R | C2912677
R69 | 0805 | 1 | 13k | C217812
R8, R9 | 0805 | 2 | 1K | C17513
RV1 | Potentiometer_Bourns_3296W_Vertical | 1 | 5M
RV6, RV7, RV8, RV9 | Potentiometer_Bourns_3296W_Vertical | 4 | 47k 10-turn | C83686
SW1 | RS 2066972 | 1 | RS 206-6972
U1, U2, U3 | HTSSOP-14-1EP_4.4x5mm_P0.65mm_EP3.4x5mm_Mask3x3.1mm_ThermalVias | 3 | DRV104 | C2150346
U10, U11, U6, U7, U8, U9 | SOT-353_SC-70-5 | 6 | 74LVC1G04 | C8207
U13, U22 | CONV_AL8861Y-13 | 2 | AL8861Y-13 | C507867
U14 | SOT-23-5 | 1 | ZXCT1110 | C78482
U15, U16, U17, U18, U19, U20, U21, U4 | Texas_HSOP-8-1EP_3.9x4.9mm_P1.27mm_ThermalVias | 8 | LMR33630ADDA | C841384
U5 | SOIC-8_3.9x4.9mm_P1.27mm | 1 | MCP6002-xSN | C7377

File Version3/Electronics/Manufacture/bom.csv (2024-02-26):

Designator | Footprint | Quantity | Value | LCSC Part #
A1 | Arduino_Nano | 1 | Arduino_Nano_v3.x
C1, C10, C11, C12, C13, C14, C18, C26, C34, C42, C50, C58, C66, C74, C9 | 0805 | 15 | 100n | C28233
C15, C19, C20, C23, C27, C28, C31, C35, C36, C39, C43, C44, C47, C51, C52, C55, C59, C60, C63, C67, C68, C71, C75, C76, C79, C81, C83 | 1206 | 27 | 10u | C13585
C16, C17, C24, C25, C32, C33, C40, C41, C48, C49, C56, C57, C64, C65, C72, C73 | 0805 | 16 | 220n | C5378
C2, C80, C82, C84 | 0402 | 4 | 10p | C32949
C21, C29, C37, C45, C53, C61, C69, C77 | CP_Elec_10x10 | 8 | 100u | C371283
C22, C3, C30, C38, C4, C46, C54, C62, C70, C78 | 0603 | 10 | 1u | C15849
C5, C6 | 0603 | 2 | 470p | C1620
C7, C8 | 0805 | 2 | 150n | C408124
D1, D11, D13, D15, D17, D19, D21, D7, D9 | 0805 | 9 | RED | C84256
D10, D12, D14, D16, D18, D20, D22, D3, D8 | 0805 | 9 | GREEN | C2297
D2 | 0805 | 1 | YELLOW | C2296
D23, D24, D25, D5, D6 | D_SMA | 5 | SS34 | C8678
D4 | 0603 | 1 | BLUE | C72041
G1 | maxlogo | 1 | LOGO
H1, H2, H3, H4, H5, H6, H7, H8 | MountingHole_4.3mm_M4 | 8 | MountingHole
J1, J12, J14, J15, J17, J19, J2, J4, J5, J7, J8 | TerminalBlock_Phoenix_PT-1,5-6-5.0-H_1x06_P5.00mm_Horizontal | 11 | Conn_01x06 | C192771
J10, J11, J13, J20 | TerminalBlock_Phoenix_PT-1,5-3-5.0-H_1x03_P5.00mm_Horizontal | 4 | Conn_01x03 | C8270
J16, J18, J3, J6 | TerminalBlock_Phoenix_PT-1,5-2-5.0-H_1x02_P5.00mm_Horizontal | 4 | Conn_01x02 | C8269
J21, J22 | DOT | 2 | Conn_01x15 | C2897378
J9 | PinHeader_1x02_P2.54mm_Vertical | 1 | Conn_01x02
JP1, JP2, JP3, JP4, JP5, JP6 | PinHeader_1x02_P2.54mm_Vertical | 6 | JUMP | C5116481
JP10, JP11, JP12, JP7, JP8, JP9 | DOT | 6 | Jumper_2_Bridged | C5305
L1, L2, L3, L4, L5, L6, L7, L8 | L_Cenker_CKST0603 | 8 | 15uH 4A | C3002650
L10, L11, L9 | L_SMMS1360 | 3 | 100uH | C149534
Q1 | TO-263-2 | 1 | LNE08R085 | C483709
R1, R65, R70, R75 | 2512 | 4 | 0.005R | C5121085
R10, R11, R16, R4, R5, R9 | 0805 | 6 | 220R | C17557
R12, R13 | 0805 | 2 | 120k | C17436
R14, R15 | 0805 | 2 | 200k | C17539
R17, R18, R21 | 0805 | 3 | 10k | C17414
R19 | 0805 | 1 | 150k | C17470
R2, R3, R66, R71, R76 | 0805 | 5 | 4.7k | C17673
R20, R22 | 0805 | 2 | 30k | C17621
R23, R27, R32, R36, R39, R42, R45 | 0805 | 7 | 47k 1% | C17713
R24 | 0805 | 1 | 8.87k 1% | C37551
R25, R28, R30, R33, R35, R38, R41, R44 | 0805 | 8 | 100k 1% | C149504
R26, R29, R31 | 0805 | 3 | 9.09k 1% | C408923
R34 | 0805 | 1 | 24.9k 1% | C234872
R37, R40, R43, R46 | 0805 | 4 | 4.3k | C204496
R47, R49, R51, R53, R55, R57, R59, R61 | 0805 | 8 | 470R | C17710
R48, R50, R52, R54, R56, R58, R60, R62 | 0805 | 8 | 560R | C28636
R6, R7 | 0805 | 2 | 1k | C17513
R63, R68, R73 | 2512 | 3 | 0.15R | C2924565
R64, R69, R74 | 2512 | 3 | 0.3R | C2912677
R67, R72, R77, R8 | 0805 | 4 | 13k | C217812
RV1 | Potentiometer_Bourns_3296W_Vertical | 1 | 5M | C780121
RV2, RV3, RV4, RV5 | Potentiometer_Bourns_3296W_Vertical | 4 | 47k 10-turn | C83686
SW1 | C3900BAAAA | 1 | C3900BAAAA | C4949944
U1, U20, U22, U24 | SOT-23-5 | 4 | ZXCT1110 | C78482
U10, U5, U6, U7, U8, U9 | SOT-353_SC-70-5 | 6 | 74LVC1G04 | C8207
U11, U12, U13, U14, U15, U16, U17, U18 | Texas_HSOP-8-1EP_3.9x4.9mm_P1.27mm_ThermalVias | 8 | LMR33630ADDA | C841384
U19, U21, U23 | TSOT-23-5 | 3 | AL8861WT-7 | C581338
U2, U3 | HTSSOP-14-1EP_4.4x5mm_P0.65mm_EP3.4x5mm_Mask3x3.1mm_ThermalVias | 2 | DRV104 | C1556572
U4 | SOIC-8_3.9x4.9mm_P1.27mm | 1 | MCP6002-xSN | C7377

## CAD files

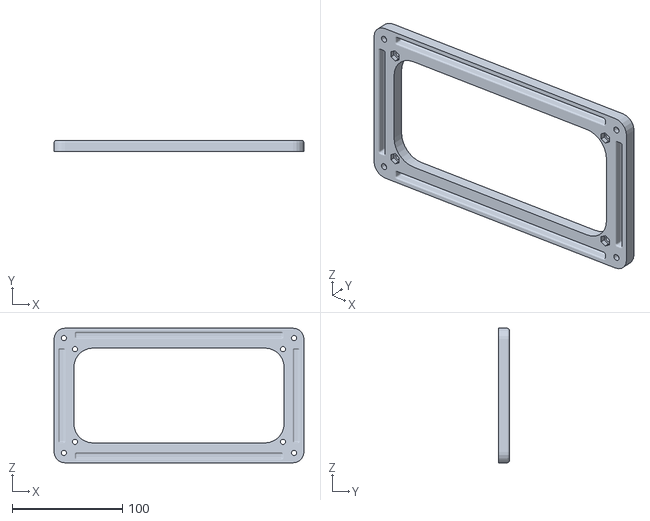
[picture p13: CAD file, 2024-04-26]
Version3/Enclosure/Enclosure_Base.stl
226.5 x 10.0 x 122.0

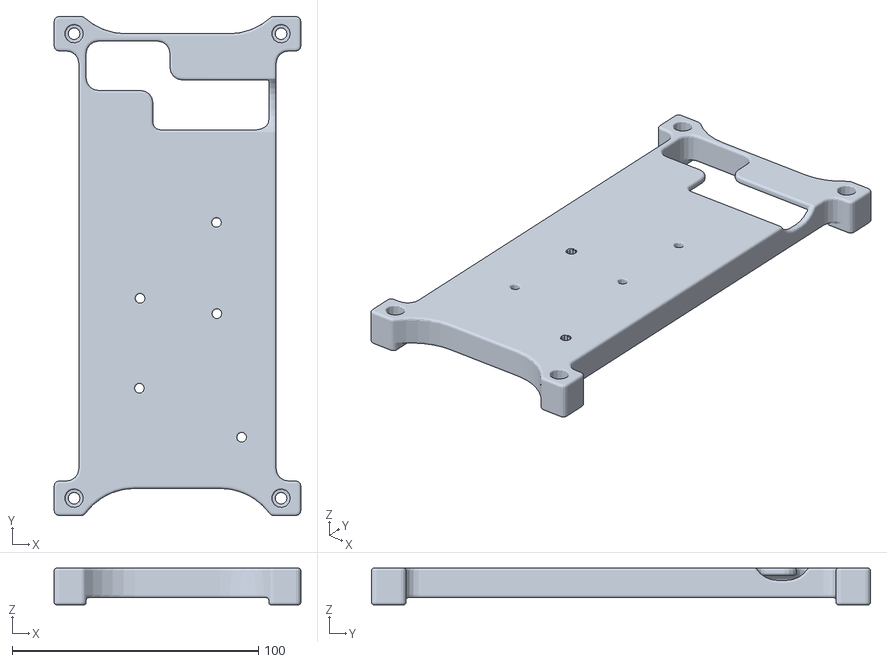
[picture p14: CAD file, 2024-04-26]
Version3/Enclosure/Enclosure_Lid.stl
100.1 x 202.5 x 15.0

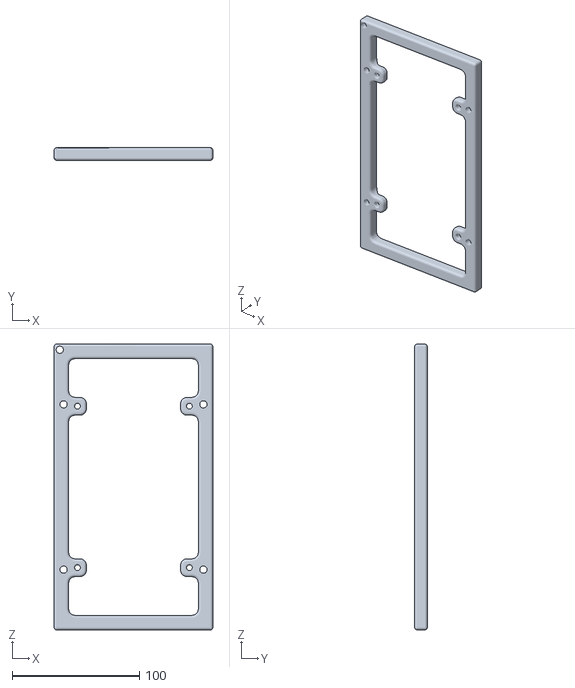
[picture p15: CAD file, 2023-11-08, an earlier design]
XLegacyVersions/Version1/Case/Case_Base.stl
125.0 x 10.0 x 225.0

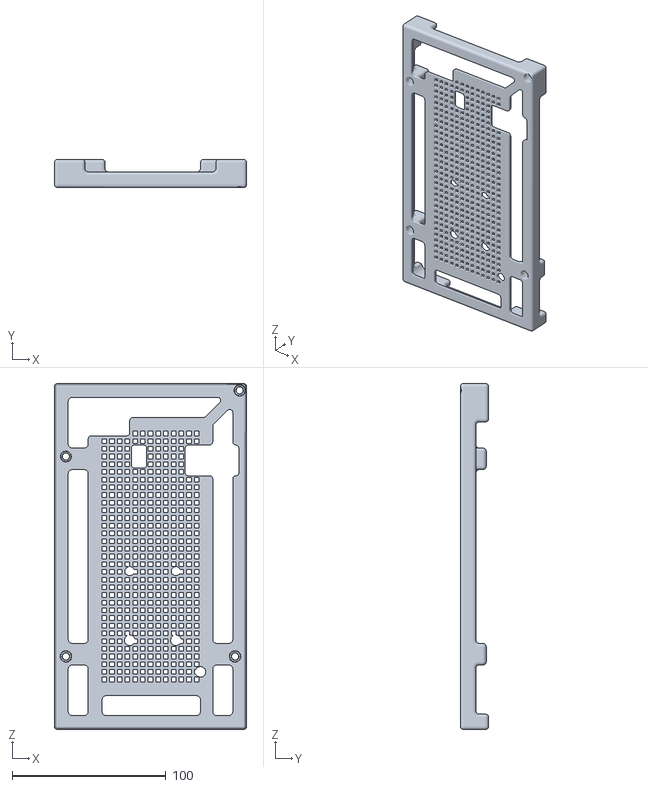
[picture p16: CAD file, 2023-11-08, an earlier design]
XLegacyVersions/Version1/Case/Case_Lid.stl
125.0 x 18.5 x 225.0

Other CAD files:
Version3/Enclosure/Enclosure_Base.ipt
Version3/Enclosure/Enclosure_Lid.ipt
XLegacyVersions/Version1/Case/Case_Base.ipt
XLegacyVersions/Version1/Case/Case_Lid.ipt

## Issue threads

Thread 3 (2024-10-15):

Firmware for V3

lfedros, 2024-10-15:
Hi Pip and Max,

we don't seem to find the firmware for the V3 board on the github. Are we missing something?

Thanks,
Federico

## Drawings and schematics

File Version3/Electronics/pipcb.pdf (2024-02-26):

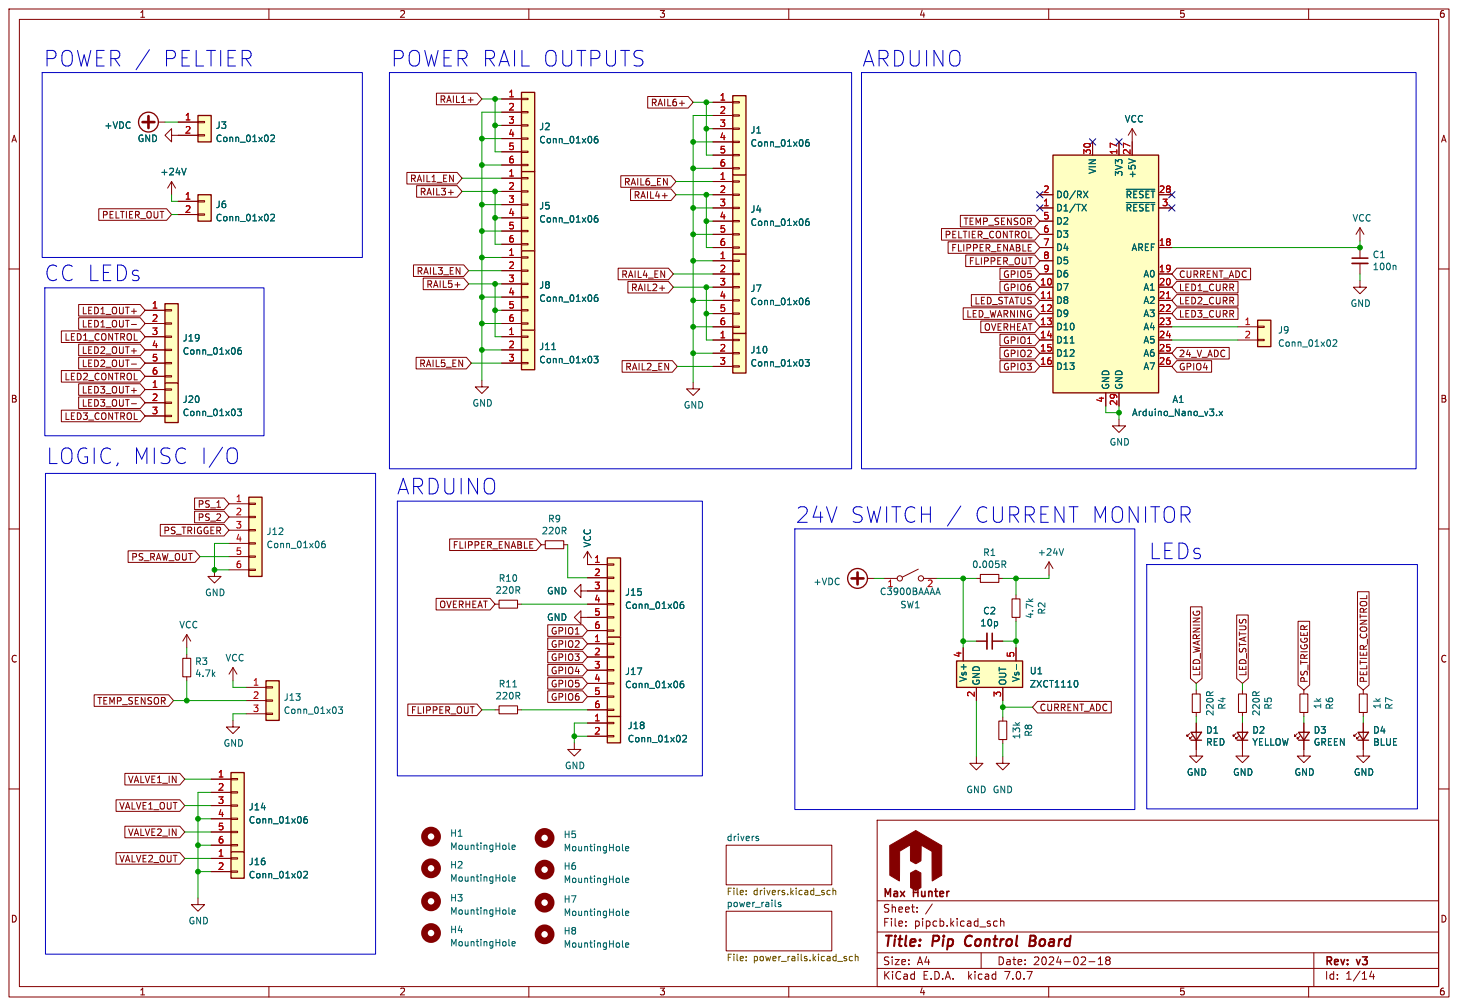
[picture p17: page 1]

drivers File: drivers.kicad_sch GND

Id: 1/14 Title: Pip Control Board

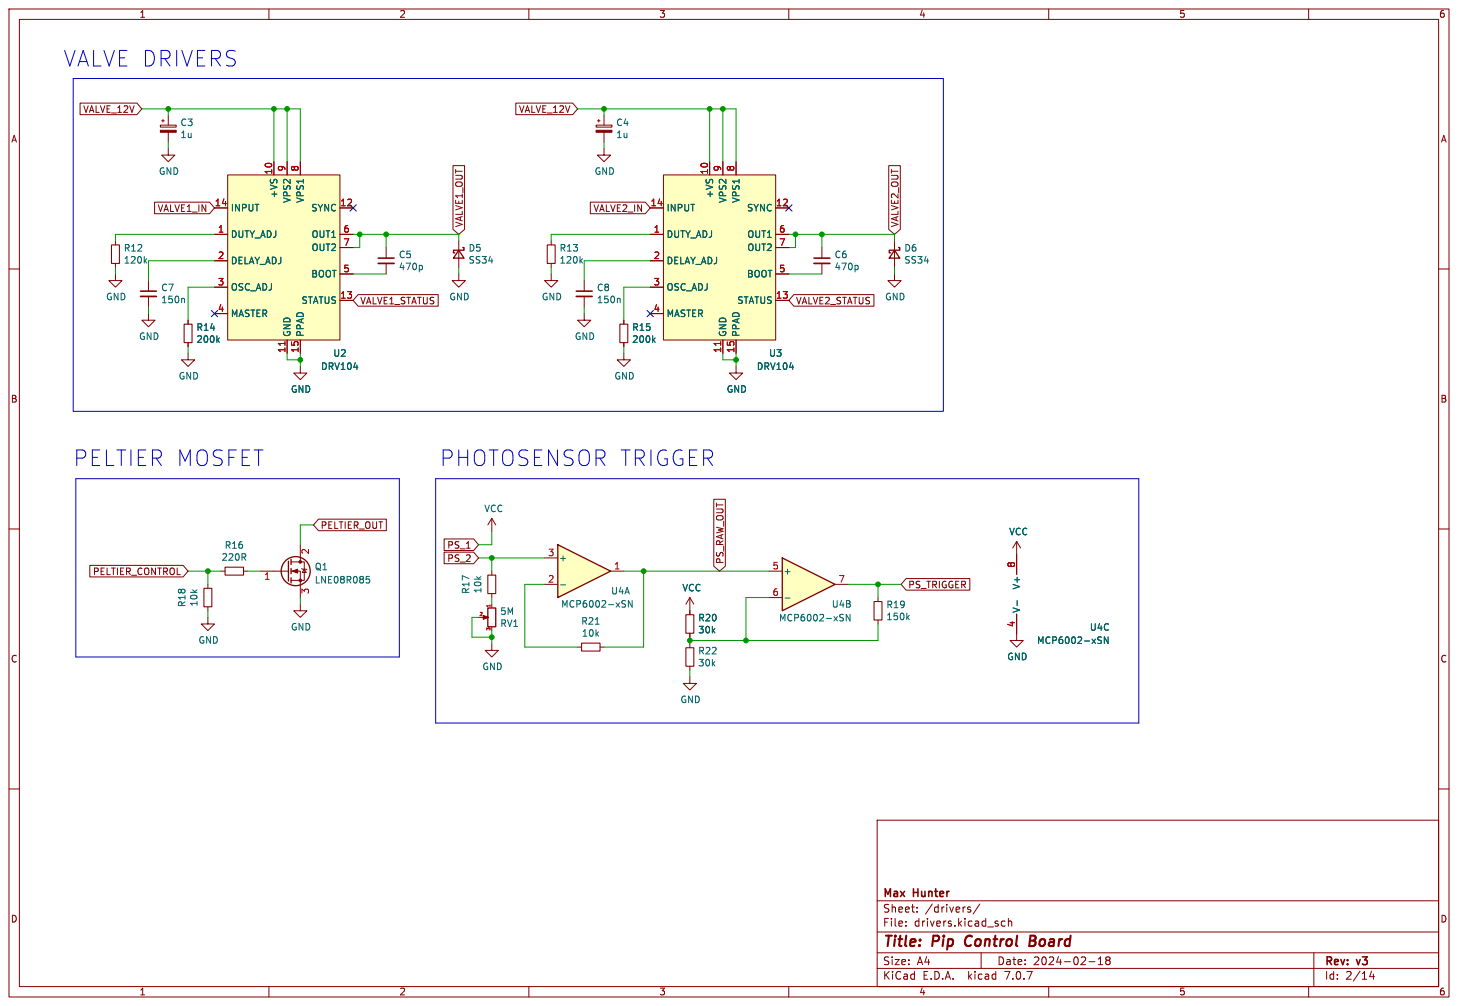
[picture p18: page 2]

Id: 2/14 Title: Pip Control Board

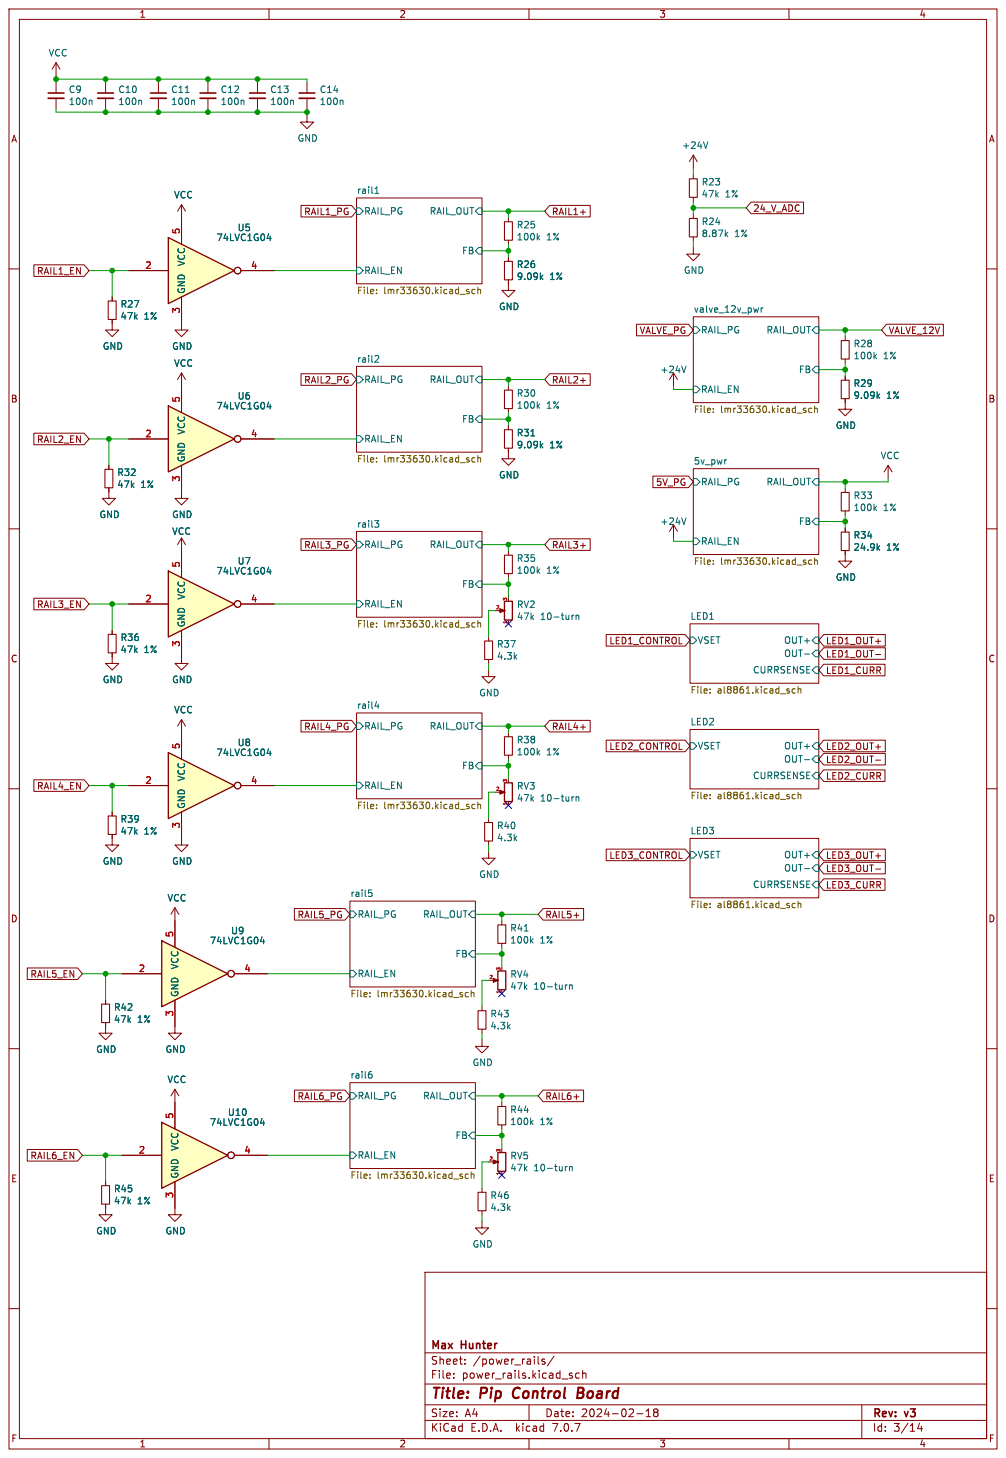
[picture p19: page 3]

5 VCC GND GND GND

Id: 3/14 Title: Pip Control Board

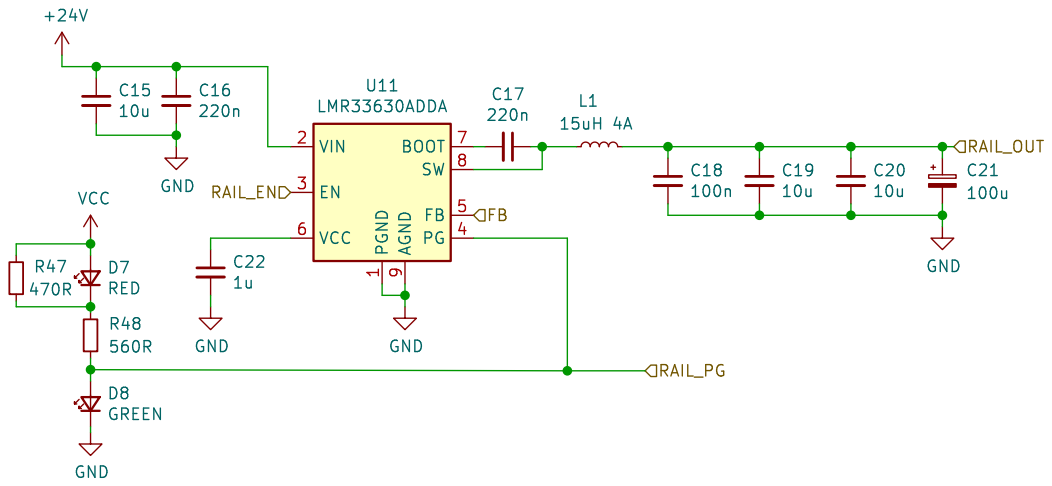
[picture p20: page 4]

1 VIN 2 EN 3 PG 4 FB 5 VCC 6 BOOT 7 SW 8 AGND

Id: 4/14 Title: Pip Control Board

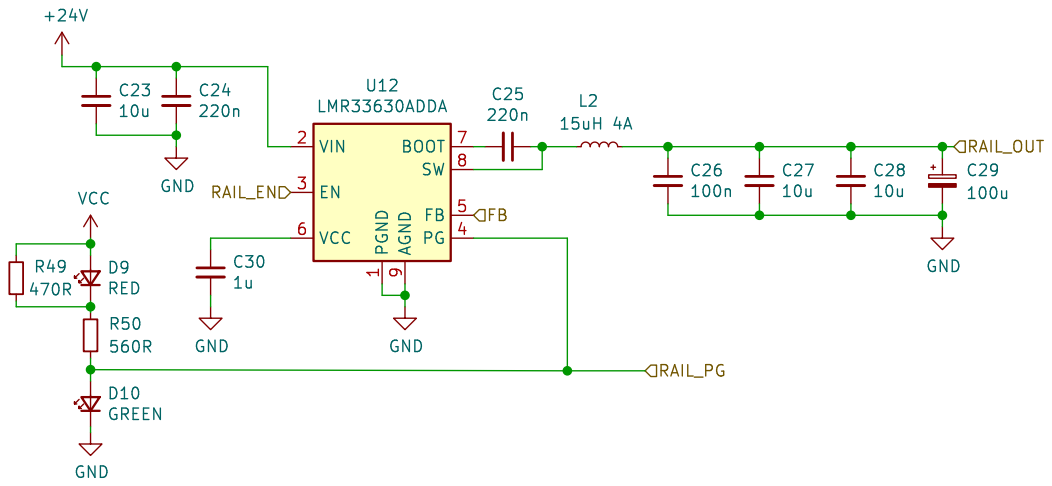
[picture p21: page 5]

1 VIN 2 EN 3 PG 4 FB 5 VCC 6 BOOT 7 SW 8 AGND

Id: 5/14 Title: Pip Control Board

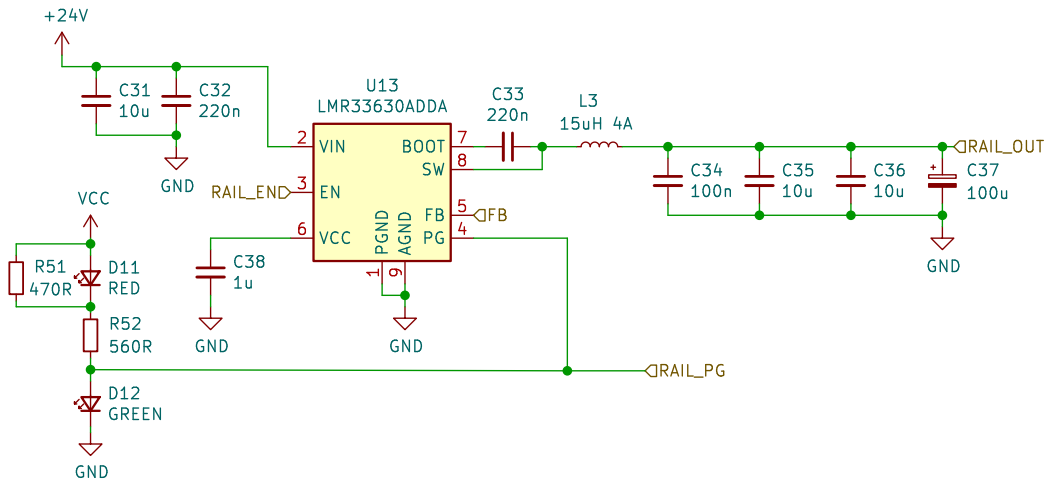
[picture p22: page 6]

1 VIN 2 EN 3 PG 4 FB 5 VCC 6 BOOT 7 SW 8 AGND

Id: 6/14 Title: Pip Control Board

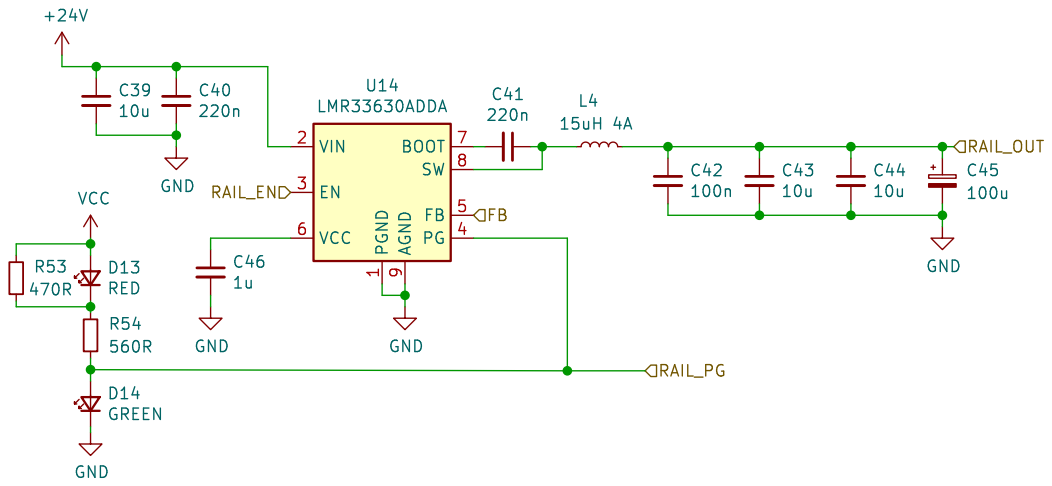
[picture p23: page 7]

1 VIN 2 EN 3 PG 4 FB 5 VCC 6 BOOT 7 SW 8 AGND

Id: 7/14 Title: Pip Control Board

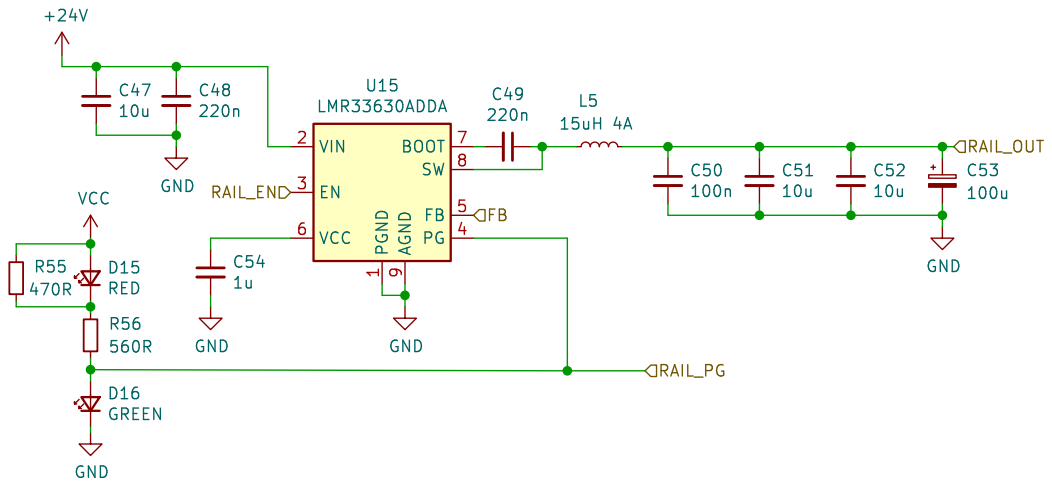
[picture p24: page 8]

1 VIN 2 EN 3 PG 4 FB 5 VCC 6 BOOT 7 SW 8 AGND

Id: 8/14 Title: Pip Control Board

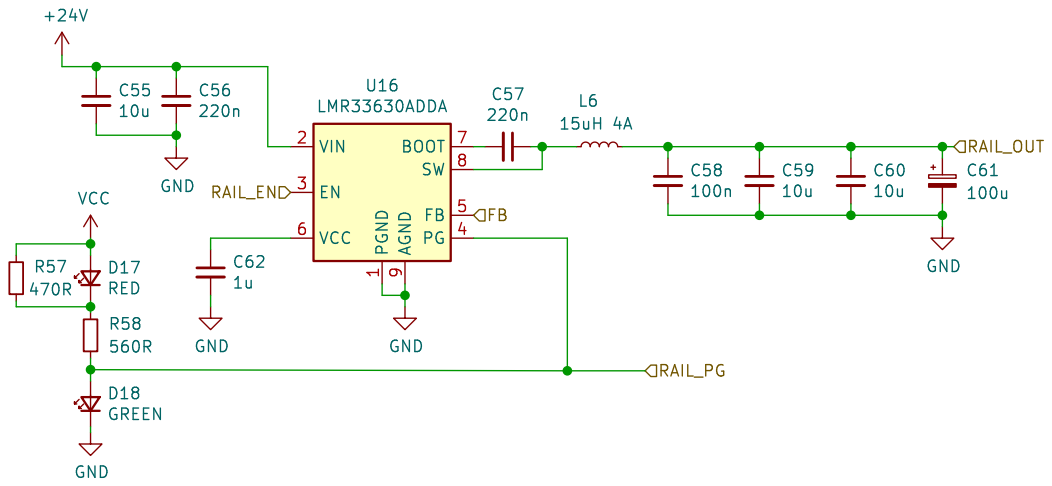
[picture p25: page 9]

1 VIN 2 EN 3 PG 4 FB 5 VCC 6 BOOT 7 SW 8 AGND

Id: 9/14 Title: Pip Control Board

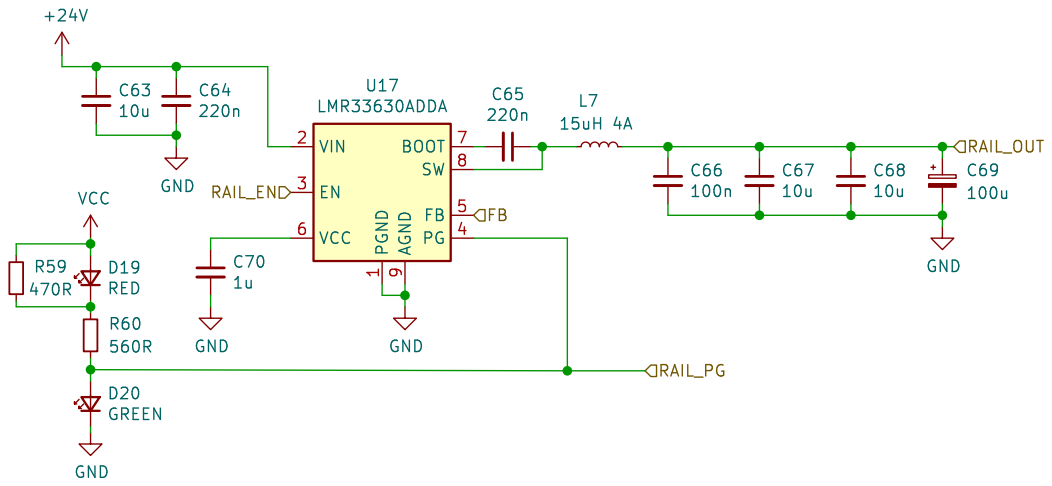
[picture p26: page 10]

1 VIN 2 EN 3 PG 4 FB 5 VCC 6 BOOT 7 SW 8 AGND

Id: 10/14 Title: Pip Control Board

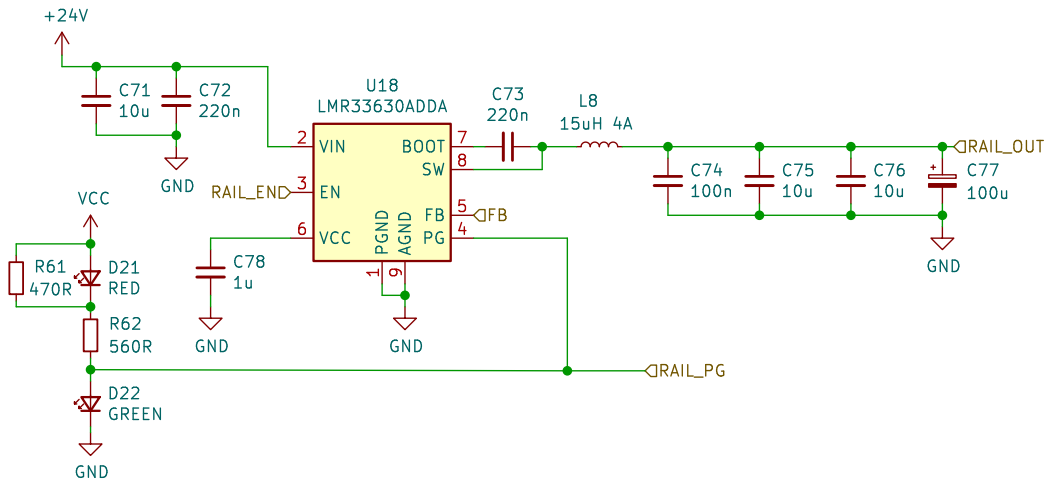
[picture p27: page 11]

1 VIN 2 EN 3 PG 4 FB 5 VCC 6 BOOT 7 SW 8 AGND

Id: 11/14 Title: Pip Control Board

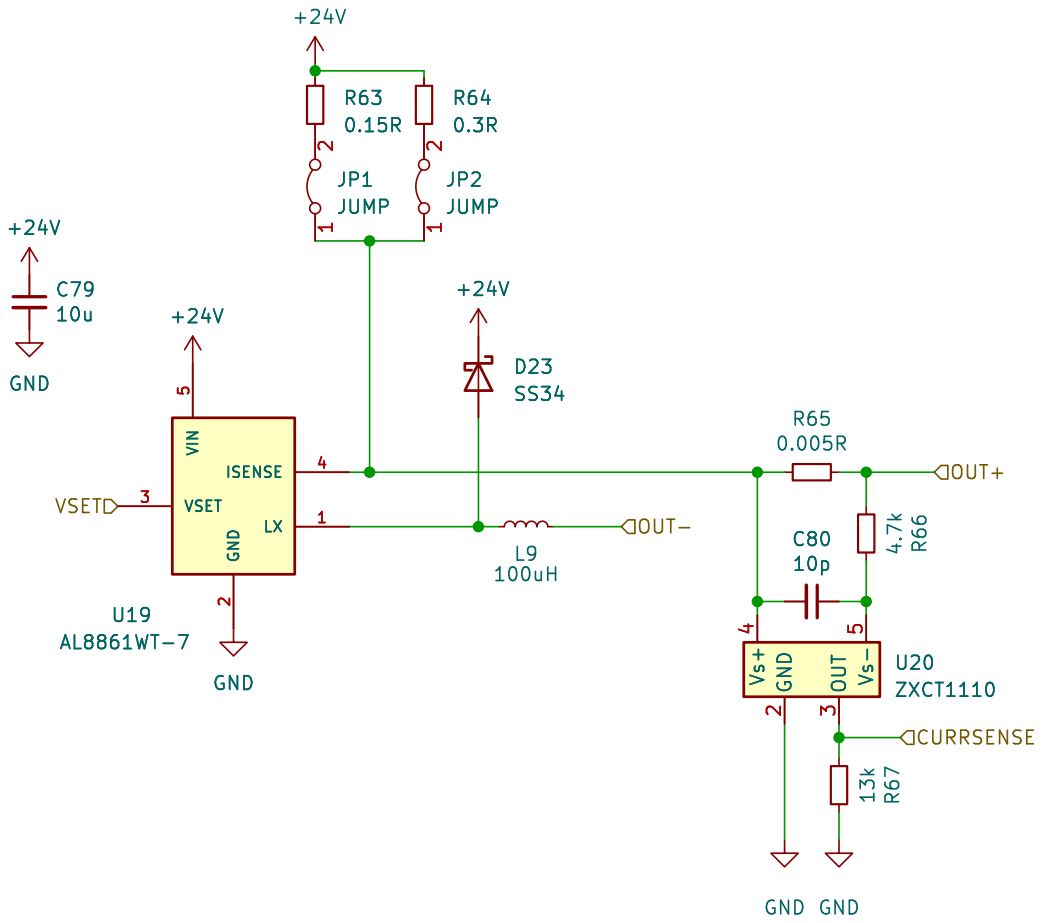
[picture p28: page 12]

Id: 12/14 Title: Pip Control Board


Id: 13/14 Title: Pip Control Board


Id: 14/14 Title: Pip Control Board

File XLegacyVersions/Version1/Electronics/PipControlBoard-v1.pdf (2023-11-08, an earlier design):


LED_STATUS RAIL2+ OVERHEAT RAIL3_GATE

GPIO1 GPIO2 RAIL5+ RAIL5_GATE RAIL4+

File: PipControlBoard.kicad_sch Sheet: / Max Hunter drivers File: drivers.kicad_sch

Id: 1/3 Title: Pip Control Board


File: drivers.kicad_sch Sheet: /drivers/ Max Hunter VCC GNDVCC 14 GND

Id: 2/3 Title: Pip Control Board


D14 SS34 GND
Sheet: /power_rails/ Max Hunter GND

File: power_rails.kicad_sch
Id: 3/3 Title: Pip Control Board

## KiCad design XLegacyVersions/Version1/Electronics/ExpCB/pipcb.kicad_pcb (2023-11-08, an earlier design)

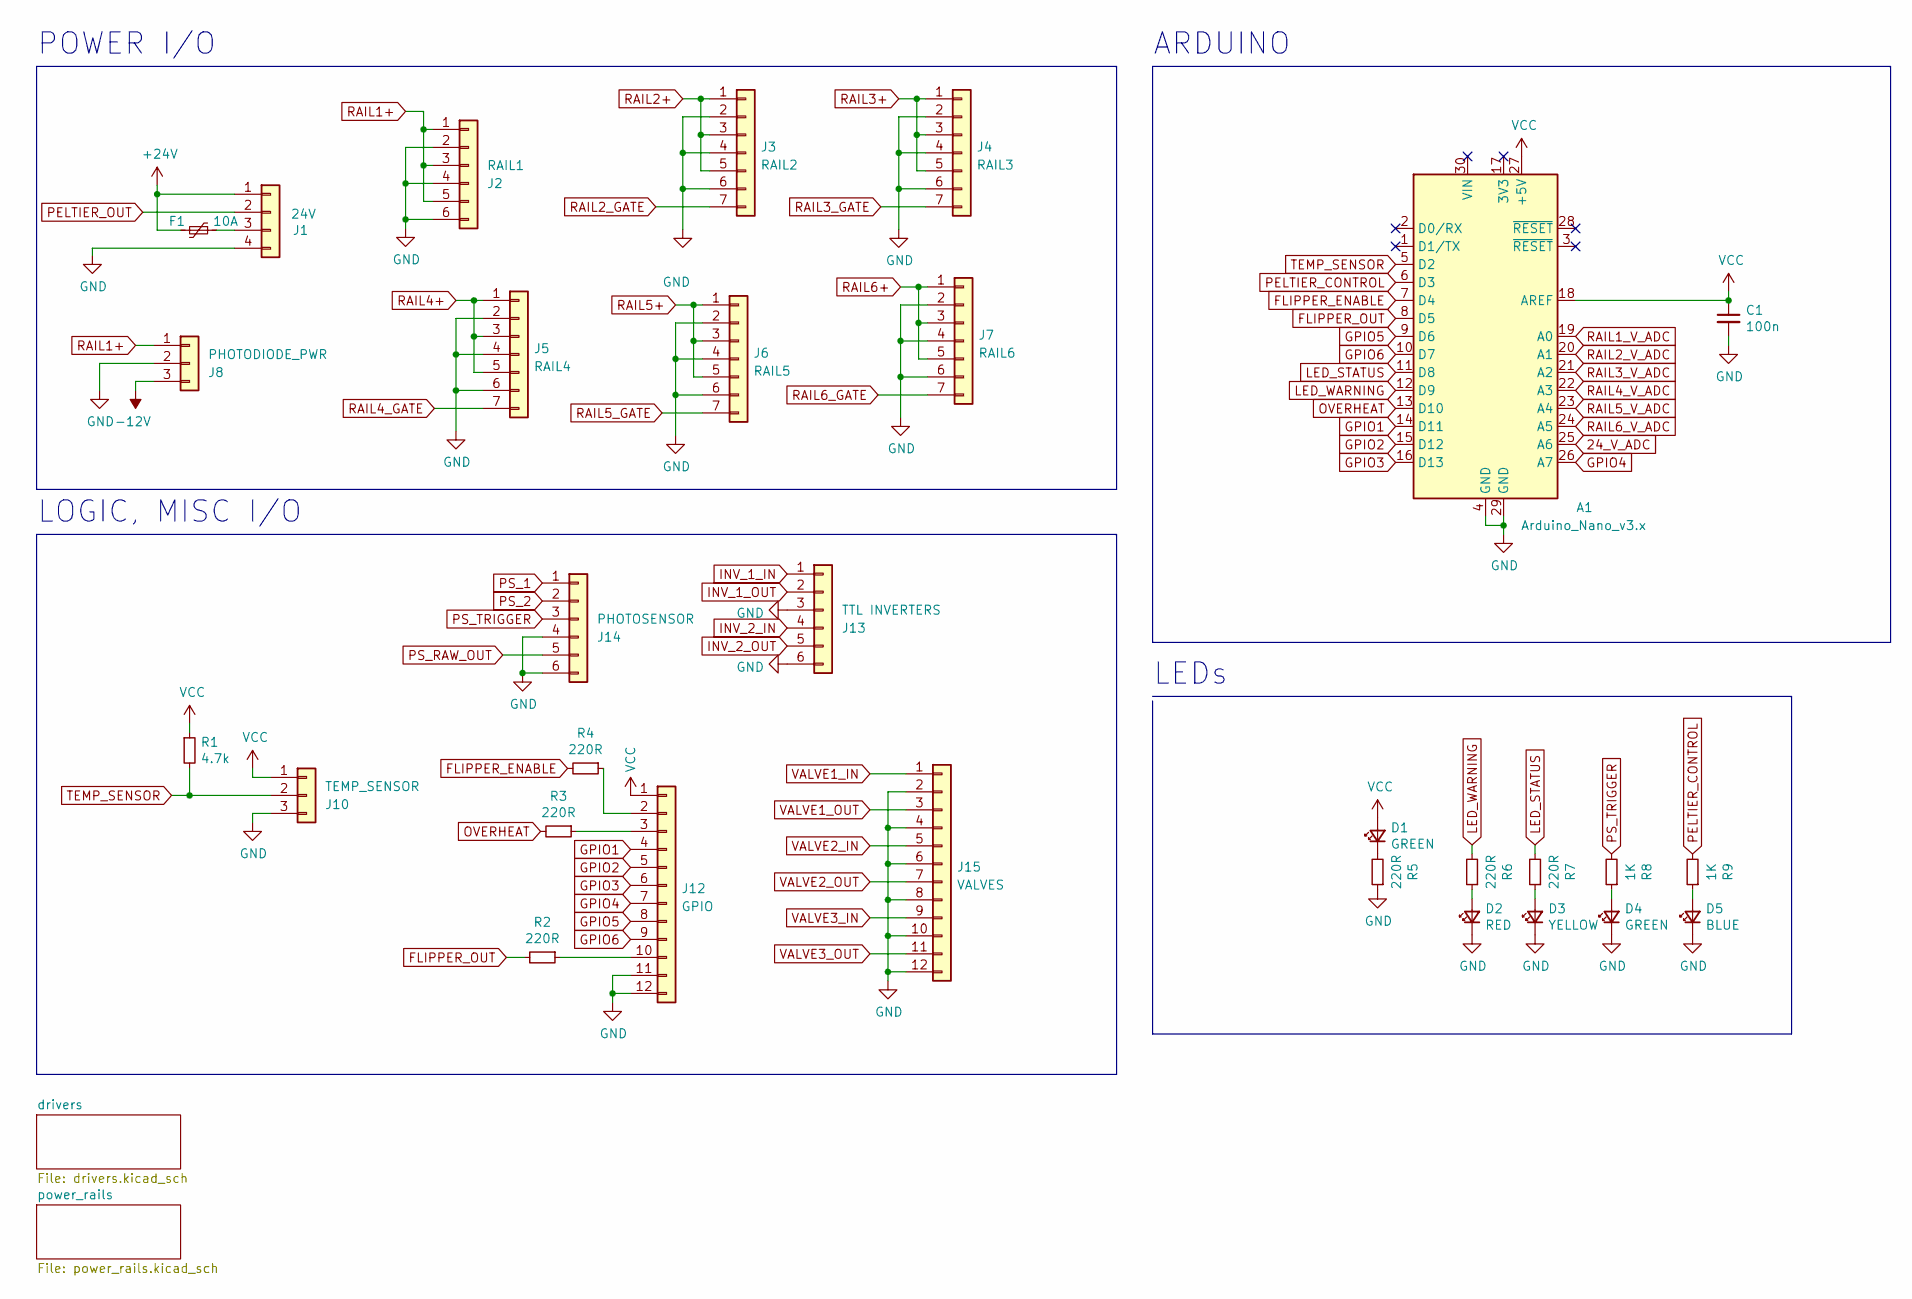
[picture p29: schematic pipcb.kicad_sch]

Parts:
A1: Arduino_Nano_v3.x; Arduino_Nano
C1: 100n; C_0805_2012Metric; LCSC Part Number C28233
D1, D4: GREEN; LED_0805_2012Metric; LCSC Part Number C2297
D2: RED; LED_0805_2012Metric; LCSC Part Number C84256
D3: YELLOW; LED_0805_2012Metric; LCSC Part Number C2296
D5: BLUE; LED_0603_1608Metric; LCSC Part Number C72041
F1: 10A; Fuse_Littelfuse-LVR100
J1: 24V; TerminalBlock_Phoenix_PT-1,5-4-5.0-H_1x04_P5.00mm_Horizontal
J2: RAIL1; TerminalBlock_Phoenix_PT-1,5-6-5.0-H_1x06_P5.00mm_Horizontal
J3: RAIL2; TerminalBlock_Phoenix_PT-1,5-7-5.0-H_1x07_P5.00mm_Horizontal
J4: RAIL3; TerminalBlock_Phoenix_PT-1,5-7-5.0-H_1x07_P5.00mm_Horizontal
J5: RAIL4; TerminalBlock_Phoenix_PT-1,5-7-5.0-H_1x07_P5.00mm_Horizontal
J6: RAIL5; TerminalBlock_Phoenix_PT-1,5-7-5.0-H_1x07_P5.00mm_Horizontal
J7: RAIL6; TerminalBlock_Phoenix_PT-1,5-7-5.0-H_1x07_P5.00mm_Horizontal
J8: PHOTODIODE_PWR; TerminalBlock_Phoenix_PT-1,5-3-5.0-H_1x03_P5.00mm_Horizontal
J10: TEMP_SENSOR; TerminalBlock_Phoenix_PT-1,5-3-5.0-H_1x03_P5.00mm_Horizontal
J12: GPIO; TerminalBlock_Phoenix_PT-1,5-12-5.0-H_1x12_P5.00mm_Horizont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
J13: TTL INVERTERS; TerminalBlock_Phoenix_PT-1,5-6-5.0-H_1x06_P5.00mm_Horizontal
J14: PHOTOSENSOR; TerminalBlock_Phoenix_PT-1,5-6-5.0-H_1x06_P5.00mm_Horizontal
J15: VALVES; TerminalBlock_Phoenix_PT-1,5-12-5.0-H_1x12_P5.00mm_Horizont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
R1: 4.7k; R_0805_2012Metric; LCSC Part Number C17673
R2, R3, R4, R5, R6, R7: 220R; R_0805_2012Metric; LCSC Part Number C17557
R8, R9: 1K; R_0805_2012Metric; LCSC Part Number C17513

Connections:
24_V_ADC: A1.25 (A6); also elsewhere on the board
+24V: F1.2, J1.1; also elsewhere on the board
-12V: J8.3; also elsewhere on the board
FLIPPER_ENABLE: A1.7 (D4), R4.2
FLIPPER_OUT: A1.8 (D5), R2.2
GND: A1.4 (GND), A1.29 (GND), C1.2, D2.1 (K), D3.1 (K), D4.1 (K), D5.1 (K), J1.4, J2.2, J2.4, J2.6, J3.2, J3.4, J3.6, J4.2, J4.4, J4.6, J5.2, J5.4, J5.6, J6.2, J6.4, J6.6, J7.2, J7.4, J7.6, J8.2, J10.3, J12.11, J12.12, J13.3, J13.6, J14.4, J14.6, J15.2, J15.4, J15.6, J15.8, J15.10, J15.12, R5.1; also elsewhere on the board
GPIO1: A1.14 (D11), J12.4
GPIO2: A1.15 (D12), J12.5
GPIO3: A1.16 (D13), J12.6
GPIO4: A1.26 (A7), J12.7
GPIO5: A1.9 (D6), J12.8
GPIO6: A1.10 (D7), J12.9
INV_1_IN: J13.1; also elsewhere on the board
INV_1_OUT: J13.2; also elsewhere on the board
INV_2_IN: J13.4; also elsewhere on the board
INV_2_OUT: J13.5; also elsewhere on the board
LED_STATUS: A1.11 (D8), R7.2
LED_WARNING: A1.12 (D9), R6.2
unnamed: D1.1 (K), R5.2
unnamed: D2.2 (A), R6.1
unnamed: D3.2 (A), R7.1
unnamed: D4.2 (A), R8.1
unnamed: D5.2 (A), R9.1
unnamed: F1.1, J1.3
unnamed: J12.2, R4.1
unnamed: J12.3, R3.1
unnamed: J12.10, R2.1
OVERHEAT: A1.13 (D10), R3.2
PELTIER_CONTROL: A1.6 (D3), R9.2; also elsewhere on the board
PELTIER_OUT: J1.2; also elsewhere on the board
PS_1: A1.18 (AREF), A1.27 (+5V), C1.1, D1.2 (A), J10.1, J12.1, J14.1, R1.1; also elsewhere on the board
PS_2: J14.2; also elsewhere on the board
PS_RAW_OUT: J14.5; also elsewhere on the board
PS_TRIGGER: J14.3, R8.2; also elsewhere on the board
RAIL1+: J2.1, J2.3, J2.5, J8.1; also elsewhere on the board
RAIL1_V_ADC: A1.19 (A0); also elsewhere on the board
RAIL2+: J3.1, J3.3, J3.5; also elsewhere on the board
RAIL2_GATE: J3.7; also elsewhere on the board
RAIL2_V_ADC: A1.20 (A1); also elsewhere on the board
RAIL3+: J4.1, J4.3, J4.5; also elsewhere on the board
RAIL3_GATE: J4.7; also elsewhere on the board
RAIL3_V_ADC: A1.21 (A2); also elsewhere on the board
RAIL4+: J5.1, J5.3, J5.5; also elsewhere on the board
RAIL4_GATE: J5.7; also elsewhere on the board
RAIL4_V_ADC: A1.22 (A3); also elsewhere on the board
RAIL5+: J6.1, J6.3, J6.5; also elsewhere on the board
RAIL5_GATE: J6.7; also elsewhere on the board
RAIL5_V_ADC: A1.23 (A4); also elsewhere on the board
RAIL6+: J7.1, J7.3, J7.5; also elsewhere on the board
RAIL6_GATE: J7.7; also elsewhere on the board
RAIL6_V_ADC: A1.24 (A5); also elsewhere on the board
TEMP_SENSOR: A1.5 (D2), J10.2, R1.2
VALVE1_IN: J15.1; also elsewhere on the board
VALVE1_OUT: J15.3; also elsewhere on the board
VALVE2_IN: J15.5; also elsewhere on the board
VALVE2_OUT: J15.7; also elsewhere on the board
VALVE3_IN: J15.9; also elsewhere on the board
VALVE3_OUT: J15.11; also elsewhere on the board

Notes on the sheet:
LEDs
ARDUINO
POWER I/O
LOGIC, MISC I/O

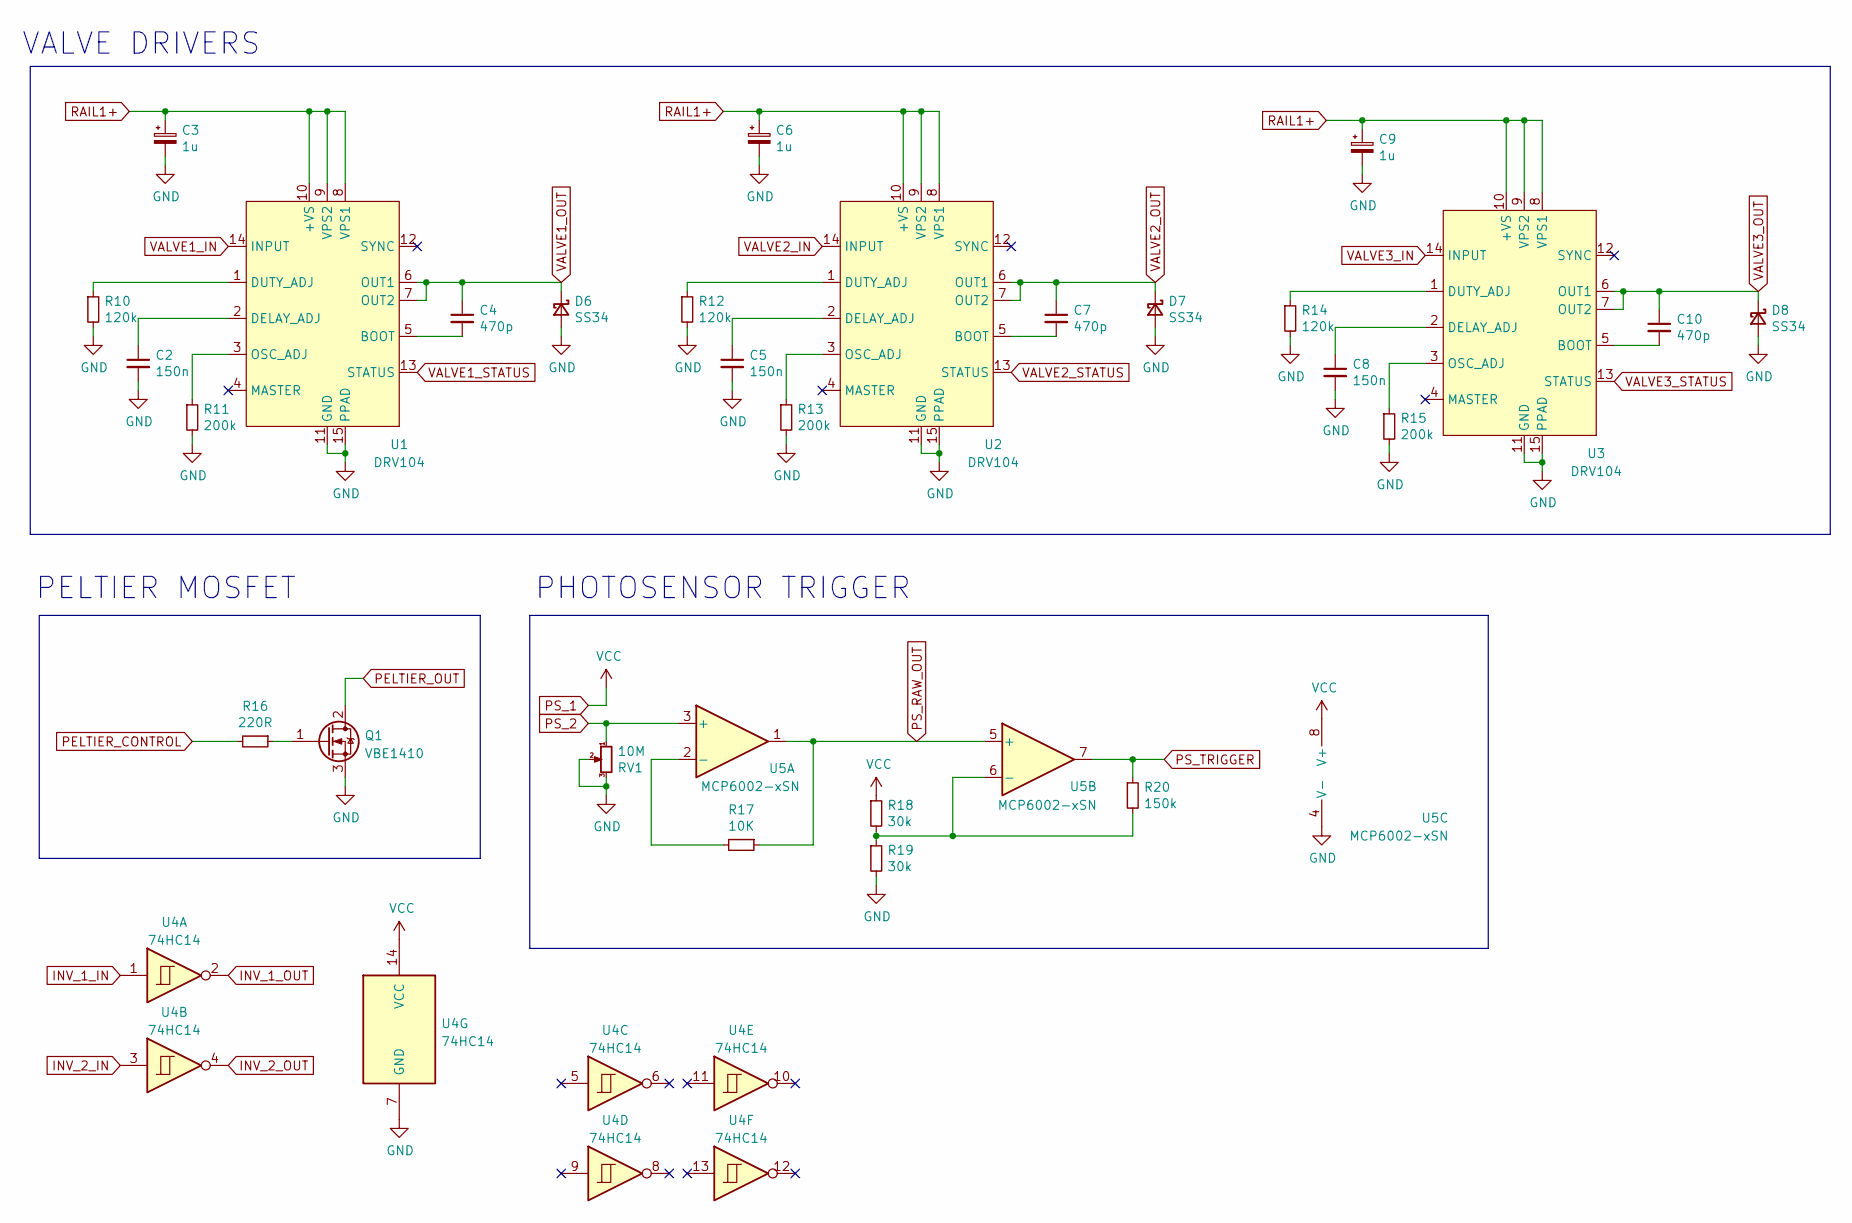
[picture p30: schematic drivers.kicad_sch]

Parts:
C2, C5, C8: 150n; C_0805_2012Metric; LCSC Part Number C1710
C3, C6, C9: 1u; C_0805_2012Metric; LCSC Part Number C28323
C4, C7, C10: 470p; C_0603_1608Metric; LCSC Part Number C1620
D6, D7, D8: SS34; D_SMA; LCSC Part Number C8678
Q1: VBE1410; TO-252-3_TabPin2; LCSC Part Number C416255
R10, R12, R14: 120k; R_0805_2012Metric; LCSC Part Number C17436
R11, R13, R15: 200k; R_0805_2012Metric; LCSC Part Number C17539
R16: 220R; R_0805_2012Metric; LCSC Part Number C17557
R17: 10K; R_0805_2012Metric; LCSC Part Number C17414
R18, R19: 30k; R_0805_2012Metric; LCSC Part Number C17621
R20: 150k; R_0805_2012Metric; LCSC Part Number C17470
RV1: 10M; Potentiometer_Bourns_3296W_Vertical; LCSC Part Number C118954
U1, U2, U3: DRV104; HTSSOP-14-1EP_4.4x5mm_P0.65mm_EP3.4x5mm_Mask3x3.1mm_Thermal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; LCSC Part Number C1556572
U4: 74HC14; SOIC-14_3.9x8.7mm_P1.27mm; LCSC Part Number C5605
U5: MCP6002-xSN; SOIC-8_3.9x4.9mm_P1.27mm; LCSC Part Number C7377

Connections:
GND: C2.2, C3.2, C5.2, C6.2, C8.2, C9.2, D6.2 (A), D7.2 (A), D8.2 (A), Q1.3 (S), R10.2, R11.2, R12.2, R13.2, R14.2, R15.2, R19.2, RV1.2, RV1.3, U1.11 (GND), U1.15 (PPAD), U2.11 (GND), U2.15 (PPAD), U3.11 (GND), U3.15 (PPAD), U4.7 (GND), U5.4 (V-); also elsewhere on the board
INV_1_IN: U4.1; also elsewhere on the board
INV_1_OUT: U4.2; also elsewhere on the board
INV_2_IN: U4.3; also elsewhere on the board
INV_2_OUT: U4.4; also elsewhere on the board
unnamed: C2.1, U1.2 (DELAY_ADJ)
unnamed: C4.2, U1.5 (BOOT)
unnamed: C5.1, U2.2 (DELAY_ADJ)
unnamed: C7.2, U2.5 (BOOT)
unnamed: C8.1, U3.2 (DELAY_ADJ)
unnamed: C10.2, U3.5 (BOOT)
unnamed: Q1.1 (G), R16.1
unnamed: R10.1, U1.1 (DUTY_ADJ)
unnamed: R11.1, U1.3 (OSC_ADJ)
unnamed: R12.1, U2.1 (DUTY_ADJ)
unnamed: R13.1, U2.3 (OSC_ADJ)
unnamed: R14.1, U3.1 (DUTY_ADJ)
unnamed: R15.1, U3.3 (OSC_ADJ)
unnamed: R17.2, U5.2 (-)
unnamed: R18.2, R19.1, R20.2, U5.6 (-)
PELTIER_CONTROL: R16.2; also elsewhere on the board
PELTIER_OUT: Q1.2 (D); also elsewhere on the board
PS_1: R18.1, U4.14 (VCC), U5.8 (V+); also elsewhere on the board
PS_2: RV1.1, U5.3 (+); also elsewhere on the board
PS_RAW_OUT: R17.1, U5.1, U5.5 (+); also elsewhere on the board
PS_TRIGGER: R20.1, U5.7; also elsewhere on the board
RAIL1+: C3.1, C6.1, C9.1, U1.8 (VPS1), U1.9 (VPS2), U1.10 (+VS), U2.8 (VPS1), U2.9 (VPS2), U2.10 (+VS), U3.8 (VPS1), U3.9 (VPS2), U3.10 (+VS); also elsewhere on the board
VALVE1_IN: U1.14 (INPUT); also elsewhere on the board
VALVE1_OUT: C4.1, D6.1 (K), U1.6 (OUT1), U1.7 (OUT2); also elsewhere on the board
VALVE1_STATUS: U1.13 (STATUS)
VALVE2_IN: U2.14 (INPUT); also elsewhere on the board
VALVE2_OUT: C7.1, D7.1 (K), U2.6 (OUT1), U2.7 (OUT2); also elsewhere on the board
VALVE2_STATUS: U2.13 (STATUS)
VALVE3_IN: U3.14 (INPUT); also elsewhere on the board
VALVE3_OUT: C10.1, D8.1 (K), U3.6 (OUT1), U3.7 (OUT2); also elsewhere on the board
VALVE3_STATUS: U3.13 (STATUS)

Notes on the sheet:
PHOTOSENSOR TRIGGER
PELTIER MOSFET
VALVE DRIVERS

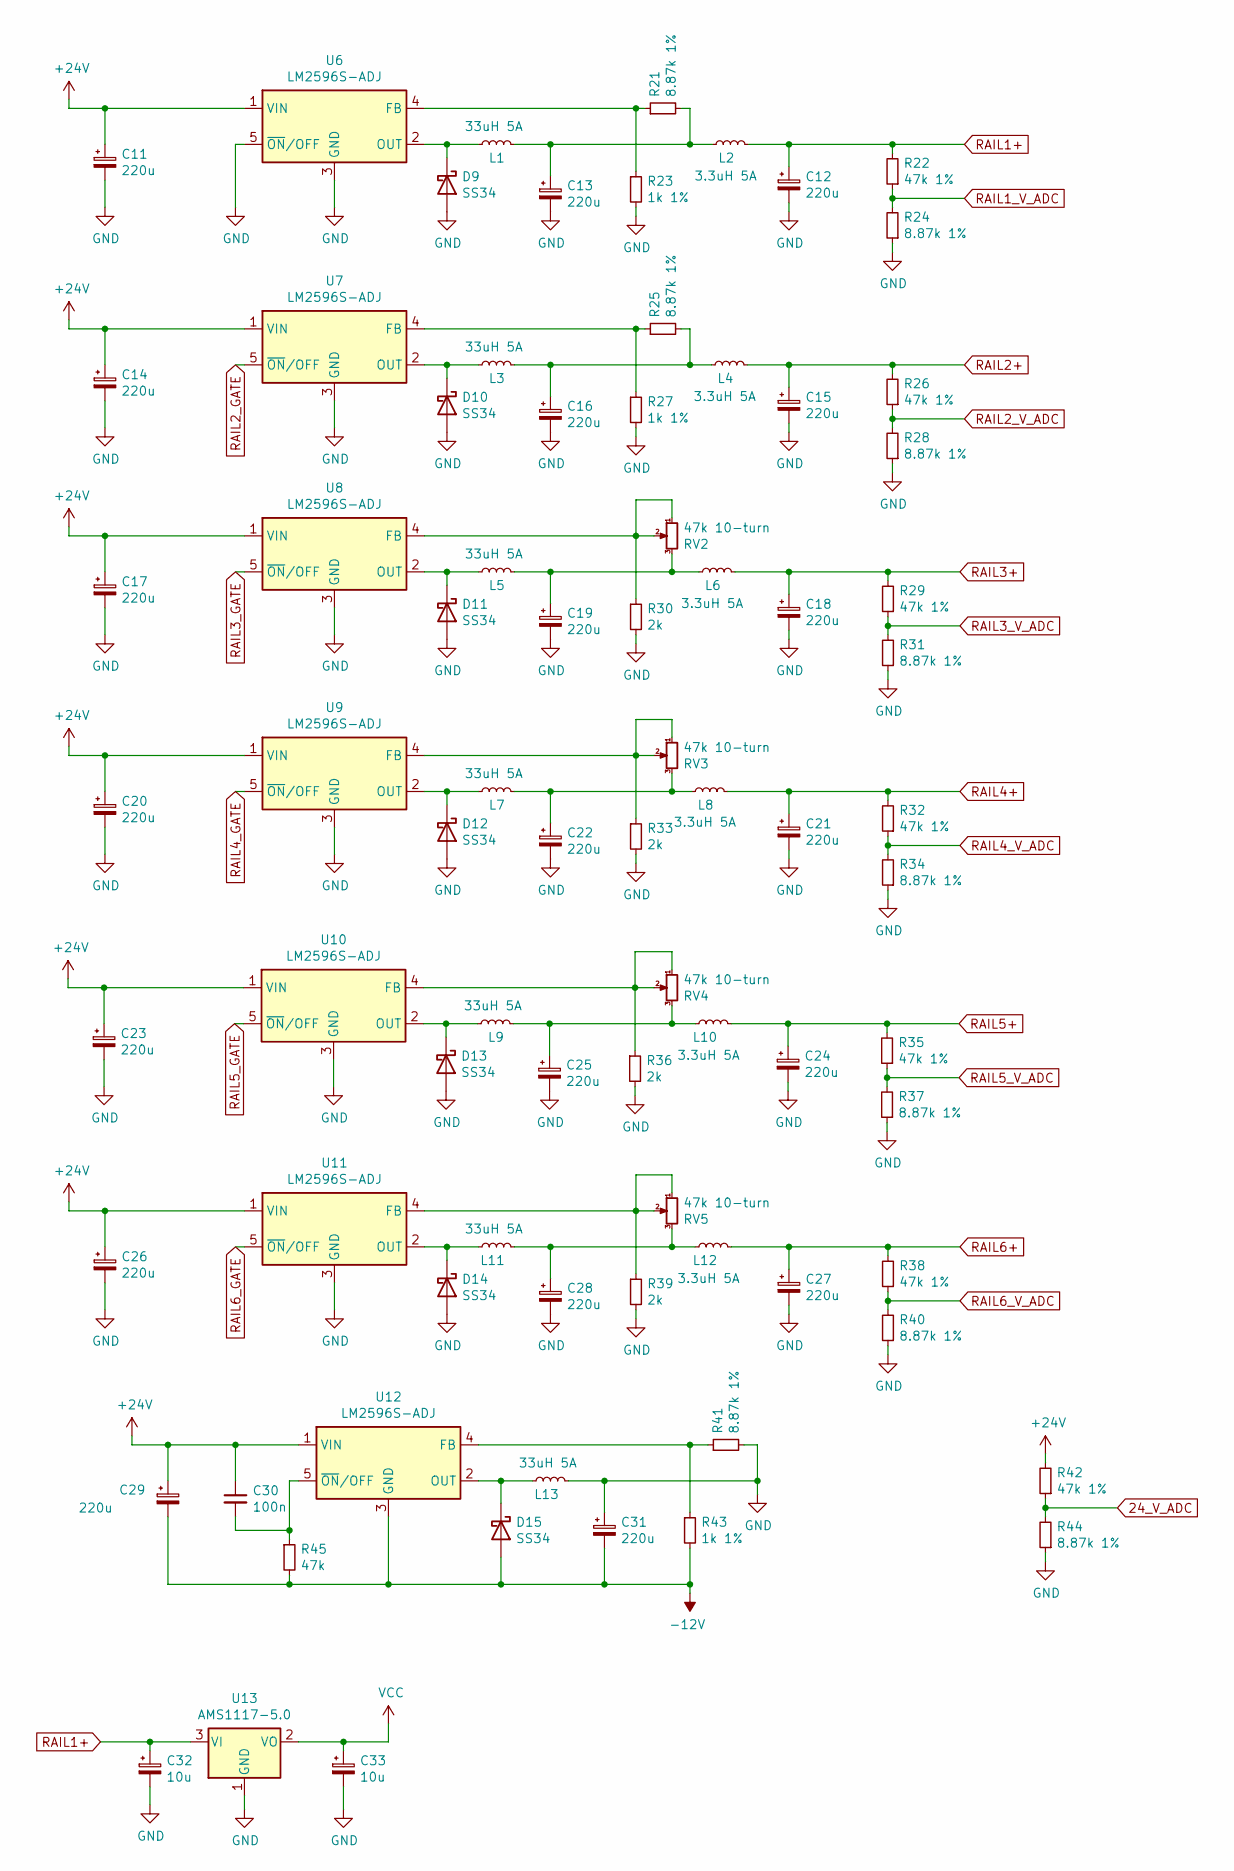
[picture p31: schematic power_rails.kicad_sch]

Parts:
C11, C12, C13, C14, C15, C16, C17, C18, C19, C20, C21, C22, C23, C24, C25, C26, C27, C28, C29, C31: 220u; CP_Elec_10x10; LCSC Part Number C125977
C30: 100n; C_0805_2012Metric; LCSC Part Number C28233
C32, C33: 10u; C_1206_3216Metric; LCSC Part Number C13585
D9, D10, D11, D12, D13, D14, D15: SS34; D_SMA; LCSC Part Number C8678
L1, L3, L5, L7, L9, L11, L13: 33uH 5A; PowerInductor_1004S; LCSC Part Number C408490
L2, L4, L6, L8, L10, L12: 3.3uH 5A; L_Sunlord_MWSA0518_5.4x5.2mm; LCSC Part Number C436534
R21, R24, R25, R28, R31, R34, R37, R40, R41, R44: 8.87k 1%; R_0805_2012Metric; LCSC Part Number C37551
R22, R26, R29, R32, R35, R38, R42: 47k 1%; R_0805_2012Metric; LCSC Part Number C17713
R23, R27, R43: 1k 1%; R_0805_2012Metric; LCSC Part Number C17513
R30, R33, R36, R39: 2k; R_0805_2012Metric; LCSC Part Number C17604
R45: 47k; R_0805_2012Metric; LCSC Part Number C17713
RV2, RV3, RV4, RV5: 47k 10-turn; Potentiometer_Bourns_3296W_Vertical; LCSC Part Number C118911
U6, U7, U8, U9, U10, U11, U12: LM2596S-ADJ; TO-263-5_TabPin3; LCSC Part Number C29781
U13: AMS1117-5.0; SOT-223-3_TabPin2; LCSC Part Number C6187

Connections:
24_V_ADC: R42.1, R44.2; also elsewhere on the board
+24V: C11.1, C14.1, C17.1, C20.1, C23.1, C26.1, C29.1, C30.1, R42.2, U6.1 (VIN), U7.1 (VIN), U8.1 (VIN), U9.1 (VIN), U10.1 (VIN), U11.1 (VIN), U12.1 (VIN); also elsewhere on the board
-12V: C29.2, C31.2, D15.2 (A), R43.2, R45.2, U12.3 (GND); also elsewhere on the board
GND: C11.2, C12.2, C13.2, C14.2, C15.2, C16.2, C17.2, C18.2, C19.2, C20.2, C21.2, C22.2, C23.2, C24.2, C25.2, C26.2, C27.2, C28.2, C31.1, C32.2, C33.2, D9.2 (A), D10.2 (A), D11.2 (A), D12.2 (A), D13.2 (A), D14.2 (A), L13.2, R23.2, R24.1, R27.2, R28.1, R30.2, R31.1, R33.2, R34.1, R36.2, R37.1, R39.2, R40.1, R41.2, R44.1, U6.3 (GND), U6.5 (~ON/OFF), U7.3 (GND), U8.3 (GND), U9.3 (GND), U10.3 (GND), U11.3 (GND), U13.1 (GND); also elsewhere on the board
unnamed: C13.1, L1.2, L2.1, R21.2
unnamed: C16.1, L3.2, L4.1, R25.2
unnamed: C19.1, L5.2, L6.1, RV2.3
unnamed: C22.1, L7.2, L8.1, RV3.3
unnamed: C25.1, L9.2, L10.1, RV4.3
unnamed: C28.1, L11.2, L12.1, RV5.3
unnamed: C30.2, R45.1, U12.5 (~ON/OFF)
unnamed: D9.1 (K), L1.1, U6.2 (OUT)
unnamed: D10.1 (K), L3.1, U7.2 (OUT)
unnamed: D11.1 (K), L5.1, U8.2 (OUT)
unnamed: D12.1 (K), L7.1, U9.2 (OUT)
unnamed: D13.1 (K), L9.1, U10.2 (OUT)
unnamed: D14.1 (K), L11.1, U11.2 (OUT)
unnamed: D15.1 (K), L13.1, U12.2 (OUT)
unnamed: R21.1, R23.1, U6.4 (FB)
unnamed: R25.1, R27.1, U7.4 (FB)
unnamed: R30.1, RV2.1, RV2.2, U8.4 (FB)
unnamed: R33.1, RV3.1, RV3.2, U9.4 (FB)
unnamed: R36.1, RV4.1, RV4.2, U10.4 (FB)
unnamed: R39.1, RV5.1, RV5.2, U11.4 (FB)
unnamed: R41.1, R43.1, U12.4 (FB)
PS_1: C33.1, U13.2 (VO); also elsewhere on the board
RAIL1+: C12.1, C32.1, L2.2, R22.2, U13.3 (VI); also elsewhere on the board
RAIL1_V_ADC: R22.1, R24.2; also elsewhere on the board
RAIL2+: C15.1, L4.2, R26.2; also elsewhere on the board
RAIL2_GATE: U7.5 (~ON/OFF); also elsewhere on the board
RAIL2_V_ADC: R26.1, R28.2; also elsewhere on the board
RAIL3+: C18.1, L6.2, R29.2; also elsewhere on the board
RAIL3_GATE: U8.5 (~ON/OFF); also elsewhere on the board
RAIL3_V_ADC: R29.1, R31.2; also elsewhere on the board
RAIL4+: C21.1, L8.2, R32.2; also elsewhere on the board
RAIL4_GATE: U9.5 (~ON/OFF); also elsewhere on the board
RAIL4_V_ADC: R32.1, R34.2; also elsewhere on the board
RAIL5+: C24.1, L10.2, R35.2; also elsewhere on the board
RAIL5_GATE: U10.5 (~ON/OFF); also elsewhere on the board
RAIL5_V_ADC: R35.1, R37.2; also elsewhere on the board
RAIL6+: C27.1, L12.2, R38.2; also elsewhere on the board
RAIL6_GATE: U11.5 (~ON/OFF); also elsewhere on the board
RAIL6_V_ADC: R38.1, R40.2; also elsewhere on the board

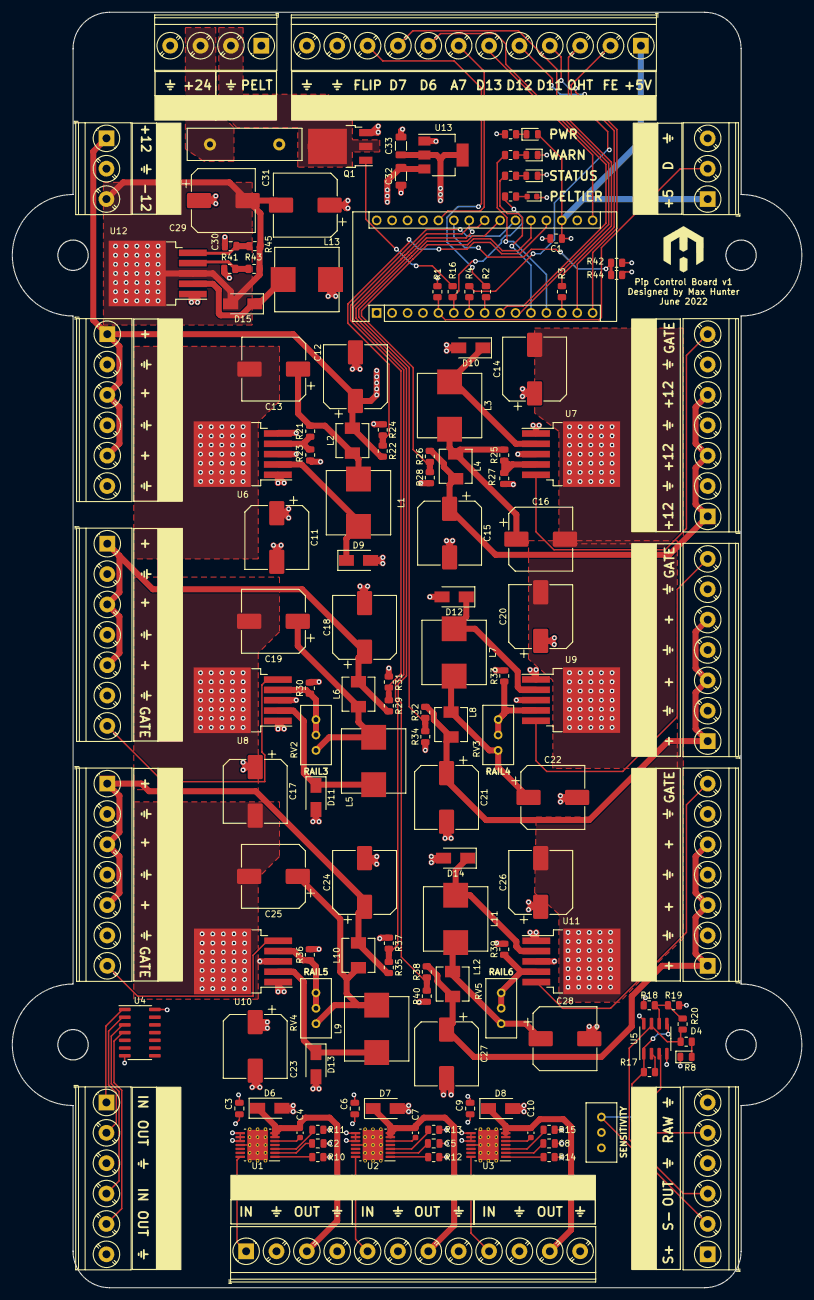
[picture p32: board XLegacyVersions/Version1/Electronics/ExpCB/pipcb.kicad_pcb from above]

Board: 4 copper layers, 130.0 x 210.0 mm, 140 parts (0 on the bottom side), 94 nets.

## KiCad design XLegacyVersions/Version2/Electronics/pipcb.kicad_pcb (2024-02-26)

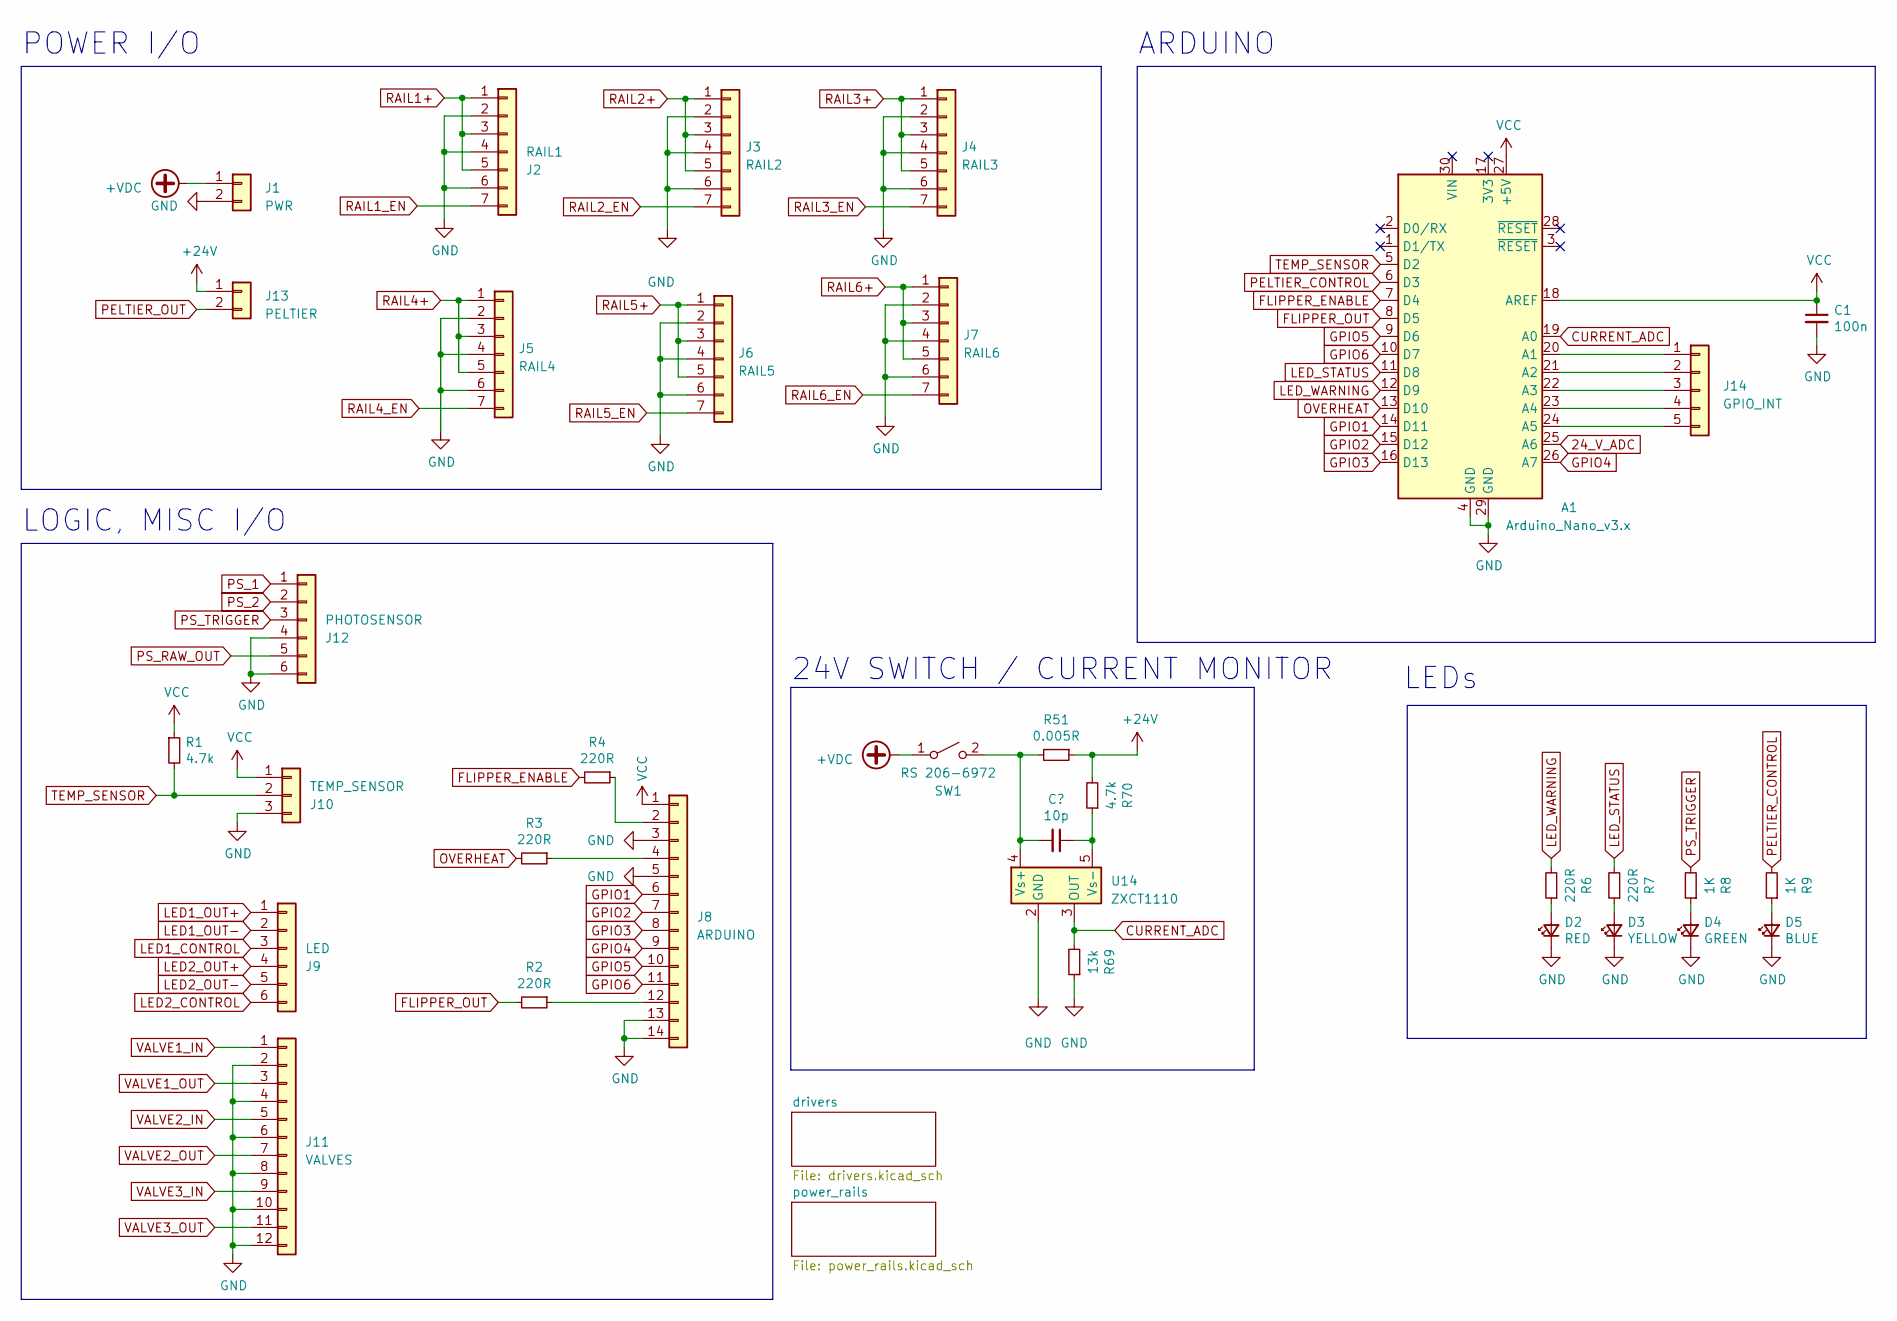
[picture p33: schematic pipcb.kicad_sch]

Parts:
A1: Arduino_Nano_v3.x; Arduino_Nano
C1: 100n; C_0805_2012Metric; LCSC Part # C28233
C36: 10p; C_0402_1005Metric; LCSC Part # C32949
D2: RED; LED_0805_2012Metric; LCSC Part # C84256
D3: YELLOW; LED_0805_2012Metric; LCSC Part # C2296
D4: GREEN; LED_0805_2012Metric; LCSC Part # C2297
D5: BLUE; LED_0603_1608Metric; LCSC Part # C72041
J1: PWR; TerminalBlock_Phoenix_PT-1,5-2-5.0-H_1x02_P5.00mm_Horizontal
J2: RAIL1; TerminalBlock_Phoenix_PT-1,5-7-5.0-H_1x07_P5.00mm_Horizontal
J3: RAIL2; TerminalBlock_Phoenix_PT-1,5-7-5.0-H_1x07_P5.00mm_Horizontal
J4: RAIL3; TerminalBlock_Phoenix_PT-1,5-7-5.0-H_1x07_P5.00mm_Horizontal
J5: RAIL4; TerminalBlock_Phoenix_PT-1,5-7-5.0-H_1x07_P5.00mm_Horizontal
J6: RAIL5; TerminalBlock_Phoenix_PT-1,5-7-5.0-H_1x07_P5.00mm_Horizontal
J7: RAIL6; TerminalBlock_Phoenix_PT-1,5-7-5.0-H_1x07_P5.00mm_Horizontal
J8: ARDUINO; TerminalBlock_Phoenix_PT-1,5-14-5.0-H_1x14_P5.00mm_Horizont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
J9: LED; TerminalBlock_Phoenix_PT-1,5-6-5.0-H_1x06_P5.00mm_Horizontal
J10: TEMP_SENSOR; TerminalBlock_Phoenix_PT-1,5-3-5.0-H_1x03_P5.00mm_Horizontal
J11: VALVES; TerminalBlock_Phoenix_PT-1,5-12-5.0-H_1x12_P5.00mm_Horizont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
J12: PHOTOSENSOR; TerminalBlock_Phoenix_PT-1,5-6-5.0-H_1x06_P5.00mm_Horizontal
J13: PELTIER; TerminalBlock_Phoenix_PT-1,5-2-5.0-H_1x02_P5.00mm_Horizontal
J14: GPIO_INT; PinHeader_1x05_P2.54mm_Vertical
R1, R70: 4.7k; R_0805_2012Metric; LCSC Part # C17673
R2, R3, R4, R6, R7: 220R; R_0805_2012Metric; LCSC Part # C17557
R8, R9: 1K; R_0805_2012Metric; LCSC Part # C17513
R51: 0.005R; R_2512_6332Metric; LCSC Part # C5121085
R69: 13k; R_0805_2012Metric; LCSC Part # C217812
SW1: RS 206-6972; RS 2066972
U14: ZXCT1110; SOT-23-5; LCSC Part # C78482

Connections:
24_V_ADC: A1.25 (A6); also elsewhere on the board
+24V: J13.1, R51.1, R70.2; also elsewhere on the board
+VDC: J1.1, SW1.1 (A)
CURRENT_ADC: A1.19 (A0), R69.2, U14.3 (OUT)
FLIPPER_ENABLE: A1.7 (D4), R4.2
FLIPPER_OUT: A1.8 (D5), R2.2
GND: A1.4 (GND), A1.29 (GND), C1.2, D2.1 (K), D3.1 (K), D4.1 (K), D5.1 (K), J1.2, J2.2, J2.4, J2.6, J3.2, J3.4, J3.6, J4.2, J4.4, J4.6, J5.2, J5.4, J5.6, J6.2, J6.4, J6.6, J7.2, J7.4, J7.6, J8.3, J8.5, J8.13, J8.14, J10.3, J11.2, J11.4, J11.6, J11.8, J11.10, J11.12, J12.4, J12.6, R69.1, U14.2 (GND); also elsewhere on the board
GPIO1: A1.14 (D11), J8.6
GPIO2: A1.15 (D12), J8.7
GPIO3: A1.16 (D13), J8.8
GPIO4: A1.26 (A7), J8.9
GPIO5: A1.9 (D6), J8.10
GPIO6: A1.10 (D7), J8.11
LED1_CONTROL: J9.3; also elsewhere on the board
LED1_OUT+: J9.1; also elsewhere on the board
LED1_OUT-: J9.2; also elsewhere on the board
LED2_CONTROL: J9.6; also elsewhere on the board
LED2_OUT+: J9.4; also elsewhere on the board
LED2_OUT-: J9.5; also elsewhere on the board
LED_STATUS: A1.11 (D8), R7.2
LED_WARNING: A1.12 (D9), R6.2
unnamed: A1.20 (A1), J14.1
unnamed: A1.21 (A2), J14.2
unnamed: A1.22 (A3), J14.3
unnamed: A1.23 (A4), J14.4
unnamed: A1.24 (A5), J14.5
unnamed: D2.2 (A), R6.1
unnamed: D3.2 (A), R7.1
unnamed: D4.2 (A), R8.1
unnamed: D5.2 (A), R9.1
unnamed: J8.2, R4.1
unnamed: J8.4, R3.1
unnamed: J8.12, R2.1
OVERHEAT: A1.13 (D10), R3.2
PELTIER_CONTROL: A1.6 (D3), R9.2; also elsewhere on the board
PELTIER_OUT: J13.2; also elsewhere on the board
PS_1: A1.18 (AREF), A1.27 (+5V), C1.1, J8.1, J10.1, J12.1, R1.1; also elsewhere on the board
PS_2: J12.2; also elsewhere on the board
PS_RAW_OUT: J12.5; also elsewhere on the board
PS_TRIGGER: J12.3, R8.2; also elsewhere on the board
RAIL1_EN: J2.7; also elsewhere on the board
RAIL2_EN: J3.7; also elsewhere on the board
RAIL3+: J4.1, J4.3, J4.5; also elsewhere on the board
RAIL3_EN: J4.7; also elsewhere on the board
RAIL4+: J5.1, J5.3, J5.5; also elsewhere on the board
RAIL4_EN: J5.7; also elsewhere on the board
RAIL5+: J6.1, J6.3, J6.5; also elsewhere on the board
RAIL5_EN: J6.7; also elsewhere on the board
RAIL6+: J7.1, J7.3, J7.5; also elsewhere on the board
RAIL6_EN: J7.7; also elsewhere on the board
TEMP_SENSOR: A1.5 (D2), J10.2, R1.2
VALVE1_IN: J11.1; also elsewhere on the board
VALVE1_OUT: J11.3; also elsewhere on the board
VALVE2_IN: J11.5; also elsewhere on the board
VALVE2_OUT: J11.7; also elsewhere on the board
VALVE3_IN: J11.9; also elsewhere on the board
VALVE3_OUT: J11.11; also elsewhere on the board

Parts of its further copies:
C98: 10p; C_0402_1005Metric; LCSC Part # C32949

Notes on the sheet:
LEDs
24V SWITCH / CURRENT MONITOR
ARDUINO
POWER I/O
LOGIC, MISC I/O

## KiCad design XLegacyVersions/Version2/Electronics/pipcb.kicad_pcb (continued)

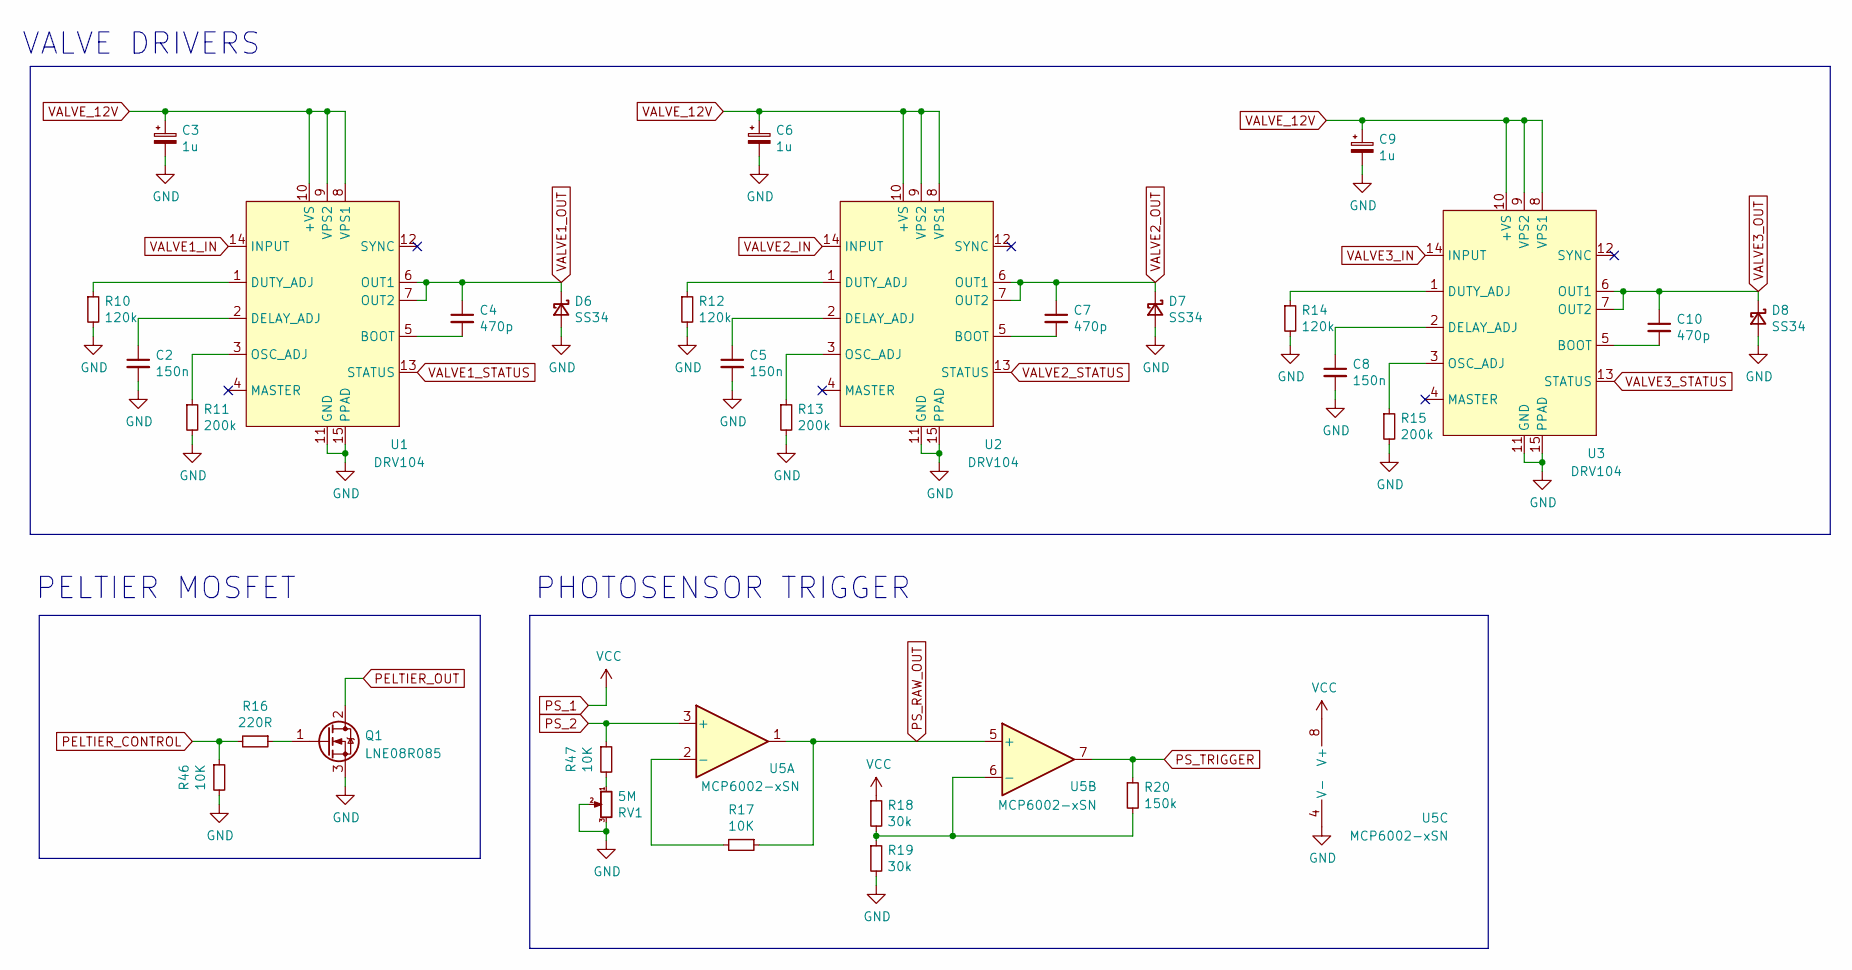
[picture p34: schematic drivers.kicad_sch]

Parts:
C2, C5, C8: 150n; C_0805_2012Metric; LCSC Part # C376934
C3, C6, C9: 1u; C_0805_2012Metric; LCSC Part # C28323
C4, C7, C10: 470p; C_0603_1608Metric; LCSC Part # C1620
D6, D7, D8: SS34; D_SMA; LCSC Part # C8678
Q1: LNE08R085; TO-263-2; LCSC Part # C483709
R10, R12, R14: 120k; R_0805_2012Metric; LCSC Part # C17436
R11, R13, R15: 200k; R_0805_2012Metric; LCSC Part # C17539
R16: 220R; R_0805_2012Metric; LCSC Part # C17557
R17, R46, R47: 10K; R_0805_2012Metric; LCSC Part # C17414
R18, R19: 30k; R_0805_2012Metric; LCSC Part # C17621
R20: 150k; R_0805_2012Metric; LCSC Part # C17470
RV1: 5M; Potentiometer_Bourns_3296W_Vertical
U1, U2, U3: DRV104; HTSSOP-14-1EP_4.4x5mm_P0.65mm_EP3.4x5mm_Mask3x3.1mm_Thermal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; LCSC Part # C2150346
U5: MCP6002-xSN; SOIC-8_3.9x4.9mm_P1.27mm; LCSC Part # C7377

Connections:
GND: C2.2, C3.2, C5.2, C6.2, C8.2, C9.2, D6.2 (A), D7.2 (A), D8.2 (A), Q1.3 (S), R10.2, R11.2, R12.2, R13.2, R14.2, R15.2, R19.2, R46.2, RV1.2, RV1.3, U1.11 (GND), U1.15 (PPAD), U2.11 (GND), U2.15 (PPAD), U3.11 (GND), U3.15 (PPAD), U5.4 (V-); also elsewhere on the board
unnamed: Q1.1 (G), R16.1
unnamed: R47.2, RV1.1
unnamed: C4.2, U1.5 (BOOT)
unnamed: C2.1, U1.2 (DELAY_ADJ)
unnamed: R10.1, U1.1 (DUTY_ADJ)
unnamed: R11.1, U1.3 (OSC_ADJ)
unnamed: C7.2, U2.5 (BOOT)
unnamed: C5.1, U2.2 (DELAY_ADJ)
unnamed: R12.1, U2.1 (DUTY_ADJ)
unnamed: R13.1, U2.3 (OSC_ADJ)
unnamed: C10.2, U3.5 (BOOT)
unnamed: C8.1, U3.2 (DELAY_ADJ)
unnamed: R14.1, U3.1 (DUTY_ADJ)
unnamed: R15.1, U3.3 (OSC_ADJ)
unnamed: R17.2, U5.2 (-)
unnamed: R18.2, R19.1, R20.2, U5.6 (-)
PELTIER_CONTROL: R16.2, R46.1; also elsewhere on the board
PELTIER_OUT: Q1.2 (D); also elsewhere on the board
PS_1: R18.1, U5.8 (V+); also elsewhere on the board
PS_2: R47.1, U5.3 (+); also elsewhere on the board
PS_RAW_OUT: R17.1, U5.1, U5.5 (+); also elsewhere on the board
PS_TRIGGER: R20.1, U5.7; also elsewhere on the board
VALVE1_IN: U1.14 (INPUT); also elsewhere on the board
VALVE1_OUT: C4.1, D6.1 (K), U1.6 (OUT1), U1.7 (OUT2); also elsewhere on the board
VALVE1_STATUS: U1.13 (STATUS)
VALVE2_IN: U2.14 (INPUT); also elsewhere on the board
VALVE2_OUT: C7.1, D7.1 (K), U2.6 (OUT1), U2.7 (OUT2); also elsewhere on the board
VALVE2_STATUS: U2.13 (STATUS)
VALVE3_IN: U3.14 (INPUT); also elsewhere on the board
VALVE3_OUT: C10.1, D8.1 (K), U3.6 (OUT1), U3.7 (OUT2); also elsewhere on the board
VALVE3_STATUS: U3.13 (STATUS)
VALVE_12V: C3.1, C6.1, C9.1, U1.8 (VPS1), U1.9 (VPS2), U1.10 (+VS), U2.8 (VPS1), U2.9 (VPS2), U2.10 (+VS), U3.8 (VPS1), U3.9 (VPS2), U3.10 (+VS); also elsewhere on the board

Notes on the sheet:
PHOTOSENSOR TRIGGER
PELTIER MOSFET
VALVE DRIVERS

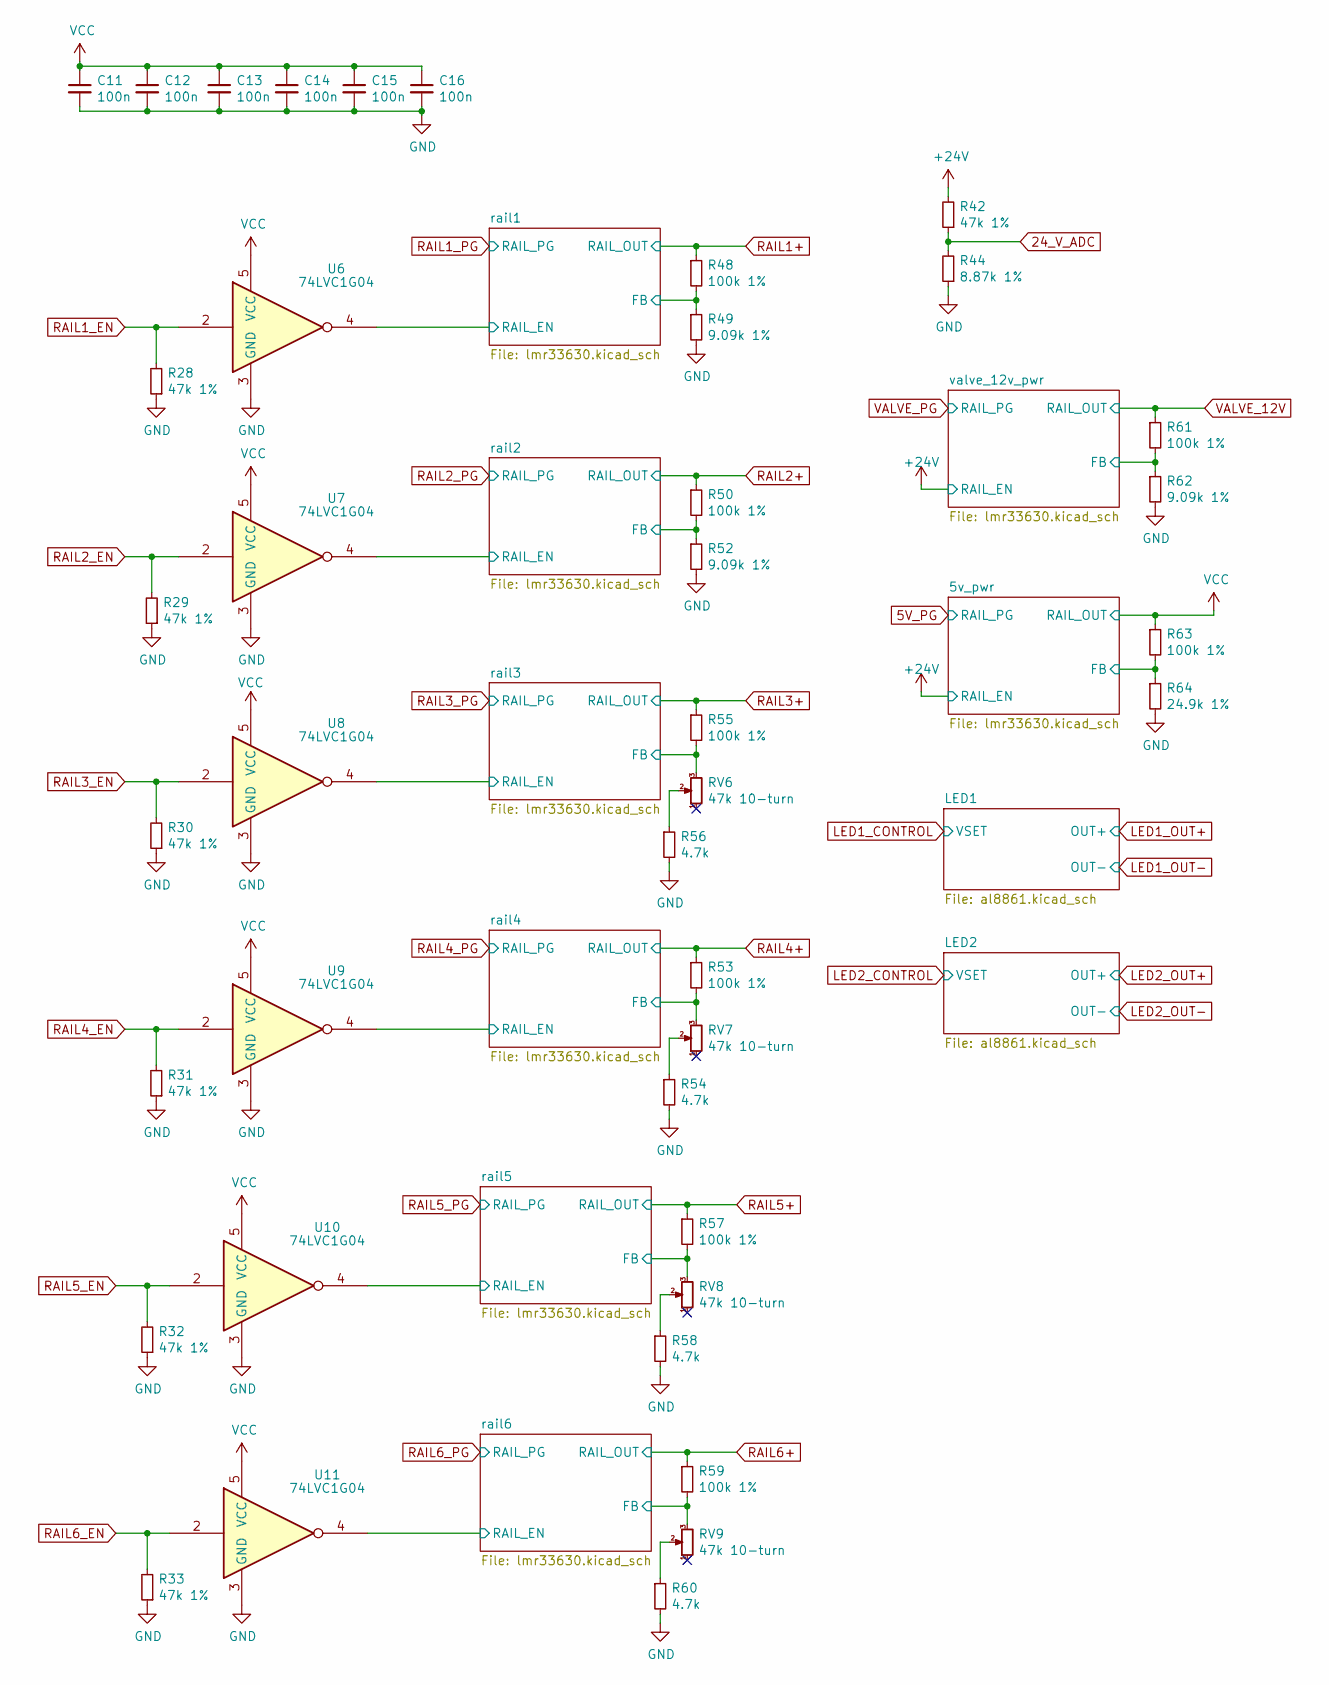
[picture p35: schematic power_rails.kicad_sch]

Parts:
C11, C12, C13, C14, C15, C16: 100n; C_0805_2012Metric; LCSC Part # C28233
R28, R29, R30, R31, R32, R33, R42: 47k 1%; R_0805_2012Metric; LCSC Part # C17713
R44: 8.87k 1%; R_0805_2012Metric; LCSC Part # C37551
R48, R50, R53, R55, R57, R59, R61, R63: 100k 1%; R_0805_2012Metric; LCSC Part # C149504
R49, R52, R62: 9.09k 1%; R_0805_2012Metric; LCSC Part # C408923
R54, R56, R58, R60: 4.7k; R_0805_2012Metric; LCSC Part # C17673
R64: 24.9k 1%; R_0805_2012Metric; LCSC Part # C234872
RV6, RV7, RV8, RV9: 47k 10-turn; Potentiometer_Bourns_3296W_Vertical; LCSC Part # C83686
U6, U7, U8, U9, U10, U11: 74LVC1G04; SOT-353_SC-70-5; LCSC Part # C8207

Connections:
24_V_ADC: R42.1, R44.2; also elsewhere on the board
+24V: R42.2; also elsewhere on the board
/power_rails/5v_pwr/FB: R63.2, R64.1; also elsewhere on the board
/power_rails/rail1/FB: R48.2, R49.1; also elsewhere on the board
/power_rails/rail1/RAIL_EN: U6.4; also elsewhere on the board
/power_rails/rail2/FB: R50.2, R52.1; also elsewhere on the board
/power_rails/rail2/RAIL_EN: U7.4; also elsewhere on the board
/power_rails/rail3/FB: R55.2, RV6.3; also elsewhere on the board
/power_rails/rail3/RAIL_EN: U8.4; also elsewhere on the board
/power_rails/rail4/FB: R53.2, RV7.3; also elsewhere on the board
/power_rails/rail4/RAIL_EN: U9.4; also elsewhere on the board
/power_rails/rail5/FB: R57.2, RV8.3; also elsewhere on the board
/power_rails/rail5/RAIL_EN: U10.4; also elsewhere on the board
/power_rails/rail6/FB: R59.2, RV9.3; also elsewhere on the board
/power_rails/rail6/RAIL_EN: U11.4; also elsewhere on the board
/power_rails/valve_12v_pwr/FB: R61.2, R62.1; also elsewhere on the board
GND: C11.2, C12.2, C13.2, C14.2, C15.2, C16.2, R28.1, R29.1, R30.1, R31.1, R32.1, R33.1, R44.1, R49.2, R52.2, R54.2, R56.2, R58.2, R60.2, R62.2, R64.2, U6.3 (GND), U7.3 (GND), U8.3 (GND), U9.3 (GND), U10.3 (GND), U11.3 (GND); also elsewhere on the board
unnamed: R54.1, RV7.2
unnamed: R56.1, RV6.2
unnamed: R58.1, RV8.2
unnamed: R60.1, RV9.2
PS_1: C11.1, C12.1, C13.1, C14.1, C15.1, C16.1, R63.1, U6.5 (VCC), U7.5 (VCC), U8.5 (VCC), U9.5 (VCC), U10.5 (VCC), U11.5 (VCC); also elsewhere on the board
RAIL1_EN: R28.2, U6.2; also elsewhere on the board
RAIL2_EN: R29.2, U7.2; also elsewhere on the board
RAIL3+: R55.1; also elsewhere on the board
RAIL3_EN: R30.2, U8.2; also elsewhere on the board
RAIL4+: R53.1; also elsewhere on the board
RAIL4_EN: R31.2, U9.2; also elsewhere on the board
RAIL5+: R57.1; also elsewhere on the board
RAIL5_EN: R32.2, U10.2; also elsewhere on the board
RAIL6+: R59.1; also elsewhere on the board
RAIL6_EN: R33.2, U11.2; also elsewhere on the board
VALVE_12V: R61.1; also elsewhere on the board

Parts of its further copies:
C45, C53, C61, C69, C77, C85, C93: 100n; C_0805_2012Metric; LCSC Part # C28233

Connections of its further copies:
GND: C45.2, C53.2, C61.2, C69.2, C77.2, C85.2, C93.2; also elsewhere on the board
PS_1: C93.1; also elsewhere on the board
RAIL3+: C53.1; also elsewhere on the board
RAIL4+: C61.1; also elsewhere on the board
RAIL5+: C69.1; also elsewhere on the board
RAIL6+: C77.1; also elsewhere on the board
VALVE_12V: C85.1; also elsewhere on the board

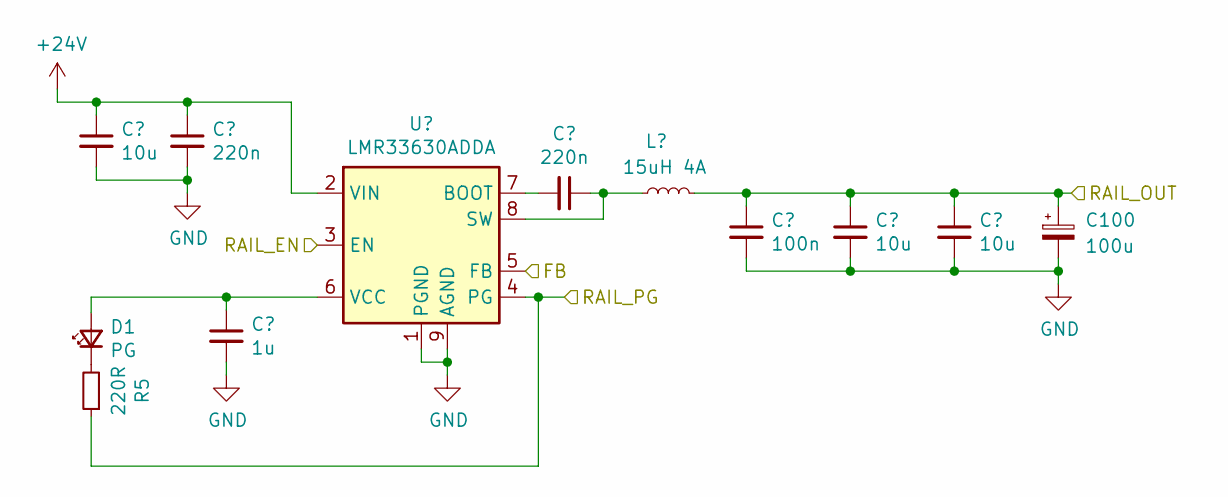
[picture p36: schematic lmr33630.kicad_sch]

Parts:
C34, C36: 220n; C_0805_2012Metric; LCSC Part # C5378
C35: 1u; C_0603_1608Metric; LCSC Part # C15849
C37, C39, C40: 10u; C_1206_3216Metric; LCSC Part # C13585
C38: 100n; C_0805_2012Metric; LCSC Part # C28233
C100: 100u; CP_Elec_10x10; LCSC Part # C371283
D1: PG; LED_0805_2012Metric; LCSC Part # C2297
L14: 15uH 4A; L_Cenker_CKST0603; LCSC Part # C3002651
R5: 220R; R_0805_2012Metric; LCSC Part # C17557
U4: LMR33630ADDA; Texas_HSOP-8-1EP_3.9x4.9mm_P1.27mm_ThermalVias; LCSC Part # C841384

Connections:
+24V: C34.1, C37.1, U4.2 (VIN); also elsewhere on the board
/power_rails/rail1/FB: U4.5 (FB); also elsewhere on the board
/power_rails/rail1/RAIL_EN: U4.3 (EN); also elsewhere on the board
GND: C34.2, C35.2, C37.2, C38.2, C39.2, C40.2, C100.2, U4.1 (PGND), U4.9 (AGND); also elsewhere on the board
unnamed: C35.1, D1.2 (A), U4.6 (VCC)
unnamed: D1.1 (K), R5.2
RAIL1_PG: R5.1, U4.4 (PG)

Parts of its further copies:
C42, C46, C47, C50, C54, C55, C58, C62, C63, C66, C70, C71, C74, C78, C79, C82, C86, C87, C90, C94, C95: 10u; C_1206_3216Metric; LCSC Part # C13585
C43, C44, C51, C52, C59, C60, C67, C68, C75, C76, C83, C84, C91, C92: 220n; C_0805_2012Metric; LCSC Part # C5378
C45, C53, C61, C69, C77, C85, C93: 100n; C_0805_2012Metric; LCSC Part # C28233
C49, C57, C65, C73, C81, C89, C97: 1u; C_0603_1608Metric; LCSC Part # C15849
C99, C101, C102, C103, C104, C105, C106: 100u; CP_Elec_10x10; LCSC Part # C371283
D9, D10, D11, D12, D13, D14, D15: PG; LED_0805_2012Metric; LCSC Part # C2297
L15, L16, L17, L18, L19, L20, L21: 15uH 4A; L_Cenker_CKST0603; LCSC Part # C3002651
R21, R22, R23, R24, R25, R26, R27: 220R; R_0805_2012Metric; LCSC Part # C17557
U15, U16, U17, U18, U19, U20, U21: LMR33630ADDA; Texas_HSOP-8-1EP_3.9x4.9mm_P1.27mm_ThermalVias; LCSC Part # C841384

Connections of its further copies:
5V_PG: R27.1, U21.4 (PG)
+24V: C42.1, C43.1, C50.1, C51.1, C58.1, C59.1, C66.1, C67.1, C74.1, C75.1, C82.1, C83.1, C90.1, C91.1, U15.2 (VIN), U16.2 (VIN), U17.2 (VIN), U18.2 (VIN), U19.2 (VIN), U20.2 (VIN), U20.3 (EN), U21.2 (VIN), U21.3 (EN); also elsewhere on the board
/power_rails/5v_pwr/FB: U21.5 (FB); also elsewhere on the board
/power_rails/rail2/FB: U15.5 (FB); also elsewhere on the board
/power_rails/rail2/RAIL_EN: U15.3 (EN); also elsewhere on the board
/power_rails/rail3/FB: U16.5 (FB); also elsewhere on the board
/power_rails/rail3/RAIL_EN: U16.3 (EN); also elsewhere on the board
/power_rails/rail4/FB: U17.5 (FB); also elsewhere on the board
/power_rails/rail4/RAIL_EN: U17.3 (EN); also elsewhere on the board
/power_rails/rail5/FB: U18.5 (FB); also elsewhere on the board
/power_rails/rail5/RAIL_EN: U18.3 (EN); also elsewhere on the board
/power_rails/rail6/FB: U19.5 (FB); also elsewhere on the board
/power_rails/rail6/RAIL_EN: U19.3 (EN); also elsewhere on the board
/power_rails/valve_12v_pwr/FB: U20.5 (FB); also elsewhere on the board
GND: C42.2, C43.2, C45.2, C46.2, C47.2, C49.2, C50.2, C51.2, C53.2, C54.2, C55.2, C57.2, C58.2, C59.2, C61.2, C62.2, C63.2, C65.2, C66.2, C67.2, C69.2, C70.2, C71.2, C73.2, C74.2, C75.2, C77.2, C78.2, C79.2, C81.2, C82.2, C83.2, C85.2, C86.2, C87.2, C89.2, C90.2, C91.2, C93.2, C94.2, C95.2, C97.2, C99.2, C101.2, C102.2, C103.2, C104.2, C105.2, C106.2, U15.1 (PGND), U15.9 (AGND), U16.1 (PGND), U16.9 (AGND), U17.1 (PGND), U17.9 (AGND), U18.1 (PGND), U18.9 (AGND), U19.1 (PGND), U19.9 (AGND), U20.1 (PGND), U20.9 (AGND), U21.1 (PGND), U21.9 (AGND); also elsewhere on the board
unnamed: C49.1, D9.2 (A), U15.6 (VCC)
unnamed: D9.1 (K), R21.2
unnamed: C57.1, D10.2 (A), U16.6 (VCC)
unnamed: D10.1 (K), R22.2
unnamed: C65.1, D11.2 (A), U17.6 (VCC)
unnamed: D11.1 (K), R23.2
unnamed: C73.1, D12.2 (A), U18.6 (VCC)
unnamed: D12.1 (K), R24.2
unnamed: C81.1, D13.2 (A), U19.6 (VCC)
unnamed: D13.1 (K), R25.2
unnamed: C89.1, D14.2 (A), U20.6 (VCC)
unnamed: D14.1 (K), R26.2
unnamed: C97.1, D15.2 (A), U21.6 (VCC)
unnamed: D15.1 (K), R27.2
unnamed: C44.2, U15.7 (BOOT)
unnamed: C44.1, L15.1, U15.8 (SW)
unnamed: C52.2, U16.7 (BOOT)
unnamed: C52.1, L16.1, U16.8 (SW)
unnamed: C60.2, U17.7 (BOOT)
unnamed: C60.1, L17.1, U17.8 (SW)
unnamed: C68.2, U18.7 (BOOT)
unnamed: C68.1, L18.1, U18.8 (SW)
unnamed: C76.2, U19.7 (BOOT)
unnamed: C76.1, L19.1, U19.8 (SW)
unnamed: C84.2, U20.7 (BOOT)
unnamed: C84.1, L20.1, U20.8 (SW)
unnamed: C92.2, U21.7 (BOOT)
unnamed: C92.1, L21.1, U21.8 (SW)
PS_1: C93.1, C94.1, C95.1, C106.1, L21.2; also elsewhere on the board
RAIL2_PG: R21.1, U15.4 (PG)
RAIL3+: C53.1, C54.1, C55.1, C101.1, L16.2; also elsewhere on the board
RAIL3_PG: R22.1, U16.4 (PG)
RAIL4+: C61.1, C62.1, C63.1, C102.1, L17.2; also elsewhere on the board
RAIL4_PG: R23.1, U17.4 (PG)
RAIL5+: C69.1, C70.1, C71.1, C103.1, L18.2; also elsewhere on the board
RAIL5_PG: R24.1, U18.4 (PG)
RAIL6+: C77.1, C78.1, C79.1, C104.1, L19.2; also elsewhere on the board
RAIL6_PG: R25.1, U19.4 (PG)
VALVE_12V: C85.1, C86.1, C87.1, C105.1, L20.2; also elsewhere on the board
VALVE_PG: R26.1, U20.4 (PG)

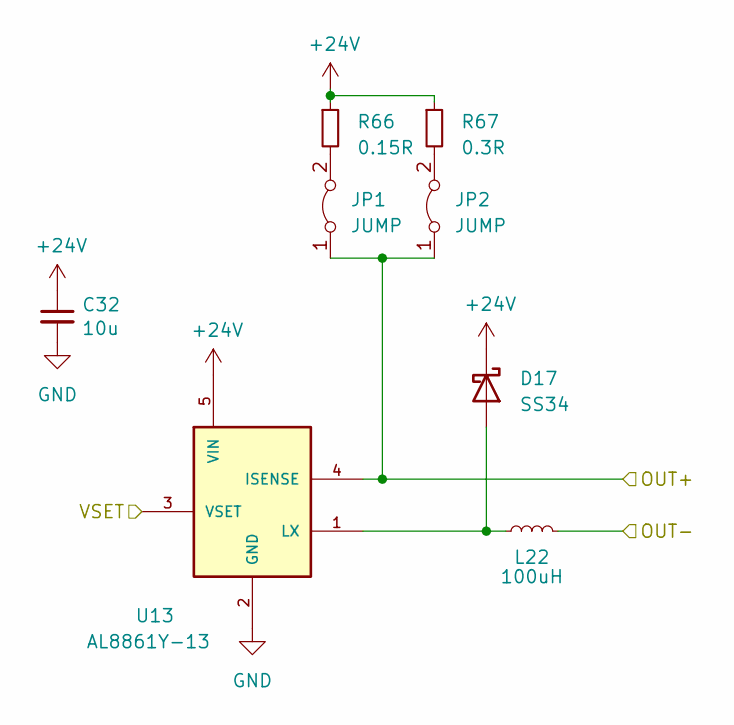
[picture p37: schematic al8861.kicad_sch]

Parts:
C32: 10u; C_1206_3216Metric; LCSC Part # C13585
D17: SS34; D_SMA; LCSC Part # C8678
JP1, JP2: JUMP; PinHeader_1x02_P2.54mm_Vertical; LCSC Part # C5305
L22: 100uH; L_SMMS1360; LCSC Part # C149534
R66: 0.15R; R_2512_6332Metric; LCSC Part # C2924565
R67: 0.3R; R_2512_6332Metric; LCSC Part # C2912677
U13: AL8861Y-13; CONV_AL8861Y-13; PARTREV 3-2; LCSC Part # C507867

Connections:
+24V: C32.1, D17.1 (K), R66.1, R67.1, U13.5 (VIN); also elsewhere on the board
GND: C32.2, U13.2 (GND); also elsewhere on the board
LED1_CONTROL: U13.3 (VSET); also elsewhere on the board
LED1_OUT+: JP1.1 (A), JP2.1 (A), U13.4 (ISENSE); also elsewhere on the board
LED1_OUT-: L22.2; also elsewhere on the board
unnamed: D17.2 (A), L22.1, U13.1 (LX)
unnamed: JP1.2 (B), R66.2
unnamed: JP2.2 (B), R67.2

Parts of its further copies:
C33, C42, C50, C58, C66, C74, C82, C90: 10u; C_1206_3216Metric; LCSC Part # C13585
D16: SS34; D_SMA; LCSC Part # C8678
JP3, JP4: JUMP; PinHeader_1x02_P2.54mm_Vertical; LCSC Part # C5305
L23: 100uH; L_SMMS1360; LCSC Part # C149534
R65: 0.15R; R_2512_6332Metric; LCSC Part # C2924565
R68: 0.3R; R_2512_6332Metric; LCSC Part # C2912677
U22: AL8861Y-13; CONV_AL8861Y-13; PARTREV 3-2; LCSC Part # C507867

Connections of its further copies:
+24V: C33.1, C42.1, C50.1, C58.1, C66.1, C74.1, C82.1, C90.1, D16.1 (K), R65.1, R68.1, U22.5 (VIN); also elsewhere on the board
GND: C33.2, C42.2, C50.2, C58.2, C66.2, C74.2, C82.2, C90.2, U22.2 (GND); also elsewhere on the board
LED2_CONTROL: U22.3 (VSET); also elsewhere on the board
LED2_OUT+: JP3.1 (A), JP4.1 (A), U22.4 (ISENSE); also elsewhere on the board
LED2_OUT-: L23.2; also elsewhere on the board
unnamed: D16.2 (A), L23.1, U22.1 (LX)
unnamed: JP3.2 (B), R65.2
unnamed: JP4.2 (B), R68.2

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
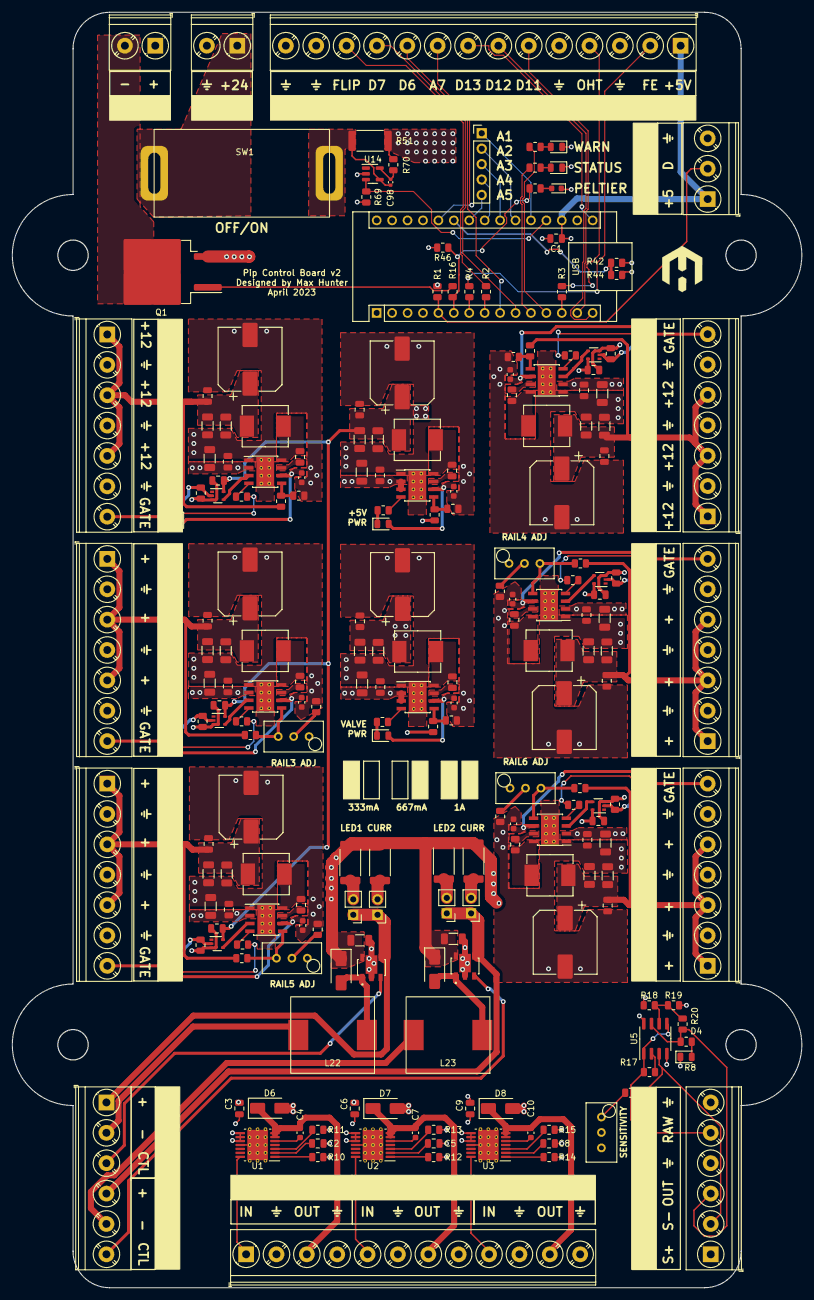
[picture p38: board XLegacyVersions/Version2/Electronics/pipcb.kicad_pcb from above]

Board: 4 copper layers, 130.0 x 210.0 mm, 217 parts (0 on the bottom side), 142 nets.

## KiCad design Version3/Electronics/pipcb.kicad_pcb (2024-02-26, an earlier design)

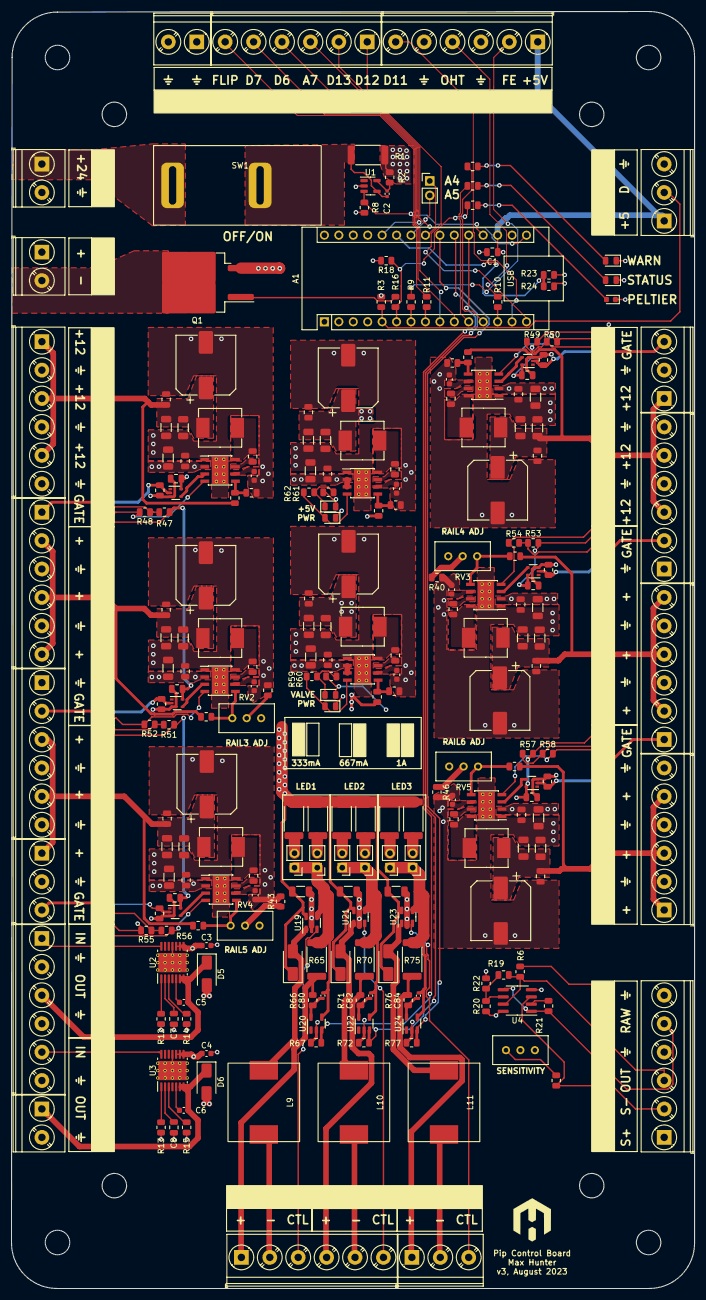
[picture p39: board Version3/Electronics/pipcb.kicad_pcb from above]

Board: 4 copper layers, 120.2 x 224.7 mm, 272 parts (0 on the bottom side), 148 nets.

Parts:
A1: Arduino_Nano_v3.x; Arduino_Nano
C1, C9, C10, C11, C12, C13, C14, C18, C26, C34, C42, C50, C58, C66, C74: 100n; C_0805_2012Metric
C2, C80, C82, C84: 10p; C_0402_1005Metric
C3, C4, C22, C30, C38, C46, C54, C62, C70, C78: 1u; C_0603_1608Metric
C5, C6: 470p; C_0603_1608Metric
C7, C8: 150n; C_0805_2012Metric
C15, C19, C20, C23, C27, C28, C31, C35, C36, C39, C43, C44, C47, C51, C52, C55, C59, C60, C63, C67, C68, C71, C75, C76, C79, C81, C83: 10u; C_1206_3216Metric
C16, C17, C24, C25, C32, C33, C40, C41, C48, C49, C56, C57, C64, C65, C72, C73: 220n; C_0805_2012Metric
C21, C29, C37, C45, C53, C61, C69, C77: 100u; CP_Elec_10x10
D1, D7, D9, D11, D13, D15, D17, D19, D21: RED; LED_0805_2012Metric
D2: YELLOW; LED_0805_2012Metric
D3, D8, D10, D12, D14, D16, D18, D20, D22: GREEN; LED_0805_2012Metric
D4: BLUE; LED_0603_1608Metric
D5, D6, D23, D24, D25: SS34; D_SMA
G1: LOGO; maxlogo
H1, H2, H3, H4, H5, H6, H7, H8: MountingHole; MountingHole_4.3mm_M4
J1, J2, J4, J5, J7, J8, J12, J14, J15, J17, J19: Conn_01x06; TerminalBlock_Phoenix_PT-1,5-6-5.0-H_1x06_P5.00mm_Horizontal
J3, J6, J16, J18: Conn_01x02; TerminalBlock_Phoenix_PT-1,5-2-5.0-H_1x02_P5.00mm_Horizontal
J9: Conn_01x02; PinHeader_1x02_P2.54mm_Vertical
J10, J11, J13, J20: Conn_01x03; TerminalBlock_Phoenix_PT-1,5-3-5.0-H_1x03_P5.00mm_Horizontal
J21, J22: Conn_01x15; DOT
JP1, JP2, JP3, JP4, JP5, JP6: JUMP; PinHeader_1x02_P2.54mm_Vertical
JP7, JP8, JP9, JP10, JP11, JP12: Jumper_2_Bridged; DOT
L1, L2, L3, L4, L5, L6, L7, L8: 15uH 4A; L_Cenker_CKST0603
L9, L10, L11: 100uH; L_SMMS1360
Q1: LNE08R085; TO-263-2
R1, R65, R70, R75: 0.005R; R_2512_6332Metric
R2, R3, R66, R71, R76: 4.7k; R_0805_2012Metric
R4, R5, R9, R10, R11, R16: 220R; R_0805_2012Metric
R6, R7: 1k; R_0805_2012Metric
R8, R67, R72, R77: 13k; R_0805_2012Metric
R12, R13: 120k; R_0805_2012Metric
R14, R15: 200k; R_0805_2012Metric
R17, R18, R21: 10k; R_0805_2012Metric
R19: 150k; R_0805_2012Metric
R20, R22: 30k; R_0805_2012Metric
R23, R27, R32, R36, R39, R42, R45: 47k 1%; R_0805_2012Metric
R24: 8.87k 1%; R_0805_2012Metric
R25, R28, R30, R33, R35, R38, R41, R44: 100k 1%; R_0805_2012Metric
R26, R29, R31: 9.09k 1%; R_0805_2012Metric
R34: 24.9k 1%; R_0805_2012Metric
R37, R40, R43, R46: 4.3k; R_0805_2012Metric
R47, R49, R51, R53, R55, R57, R59, R61: 470R; R_0805_2012Metric
R48, R50, R52, R54, R56, R58, R60, R62: 560R; R_0805_2012Metric
R63, R68, R73: 0.15R; R_2512_6332Metric
R64, R69, R74: 0.3R; R_2512_6332Metric
RV2, RV3, RV4, RV5: 47k 10-turn; Potentiometer_Bourns_3296W_Vertical
SW1: C3900BAAAA
U1, U20, U22, U24: ZXCT1110; SOT-23-5
U2, U3: DRV104; HTSSOP-14-1EP_4.4x5mm_P0.65mm_EP3.4x5mm_Mask3x3.1mm_Thermal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
U4: MCP6002-xSN; SOIC-8_3.9x4.9mm_P1.27mm
U5, U6, U7, U8, U9, U10: 74LVC1G04; SOT-353_SC-70-5
U11, U12, U13, U14, U15, U16, U17, U18: LMR33630ADDA; Texas_HSOP-8-1EP_3.9x4.9mm_P1.27mm_ThermalVias
U19, U21, U23: AL8861WT-7; TSOT-23-5
locked: 5M; Potentiometer_Bourns_3296W_Vertical

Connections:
5V_PG: D22.2 (A), R62.2, U18.4 (PG)
24_V_ADC: A1.25 (A6), R23.1, R24.2
+24V: C15.1, C16.1, C23.1, C24.1, C31.1, C32.1, C39.1, C40.1, C47.1, C48.1, C55.1, C56.1, C63.1, C64.1, C71.1, C72.1, C79.1, C81.1, C83.1, D23.1 (K), D24.1 (K), D25.1 (K), J6.1, R1.1, R2.2, R23.2, R63.1, R64.1, R68.1, R69.1, R73.1, R74.1, U11.2 (VIN), U12.2 (VIN), U13.2 (VIN), U14.2 (VIN), U15.2 (VIN), U16.2 (VIN), U17.2 (VIN), U17.3 (EN), U18.2 (VIN), U18.3 (EN), U19.5 (VIN), U21.5 (VIN), U23.5 (VIN)
+VDC: J3.1, SW1.1 (A)
/power_rails/5v_pwr/FB: R33.2, R34.1, U18.5 (FB)
/power_rails/rail1/FB: R25.2, R26.1, U11.5 (FB)
/power_rails/rail1/RAIL_EN: U5.4, U11.3 (EN)
/power_rails/rail2/FB: R30.2, R31.1, U12.5 (FB)
/power_rails/rail2/RAIL_EN: U6.4, U12.3 (EN)
/power_rails/rail3/FB: R35.2, RV2.3, U13.5 (FB)
/power_rails/rail3/RAIL_EN: U7.4, U13.3 (EN)
/power_rails/rail4/FB: R38.2, RV3.3, U14.5 (FB)
/power_rails/rail4/RAIL_EN: U8.4, U14.3 (EN)
/power_rails/rail5/FB: R41.2, RV4.3, U15.5 (FB)
/power_rails/rail5/RAIL_EN: U9.4, U15.3 (EN)
/power_rails/rail6/FB: R44.2, RV5.3, U16.5 (FB)
/power_rails/rail6/RAIL_EN: U10.4, U16.3 (EN)
/power_rails/valve_12v_pwr/FB: R28.2, R29.1, U17.5 (FB)
CURRENT_ADC: A1.19 (A0), R8.2, U1.3 (OUT)
FLIPPER_ENABLE: A1.7 (D4), R9.2
FLIPPER_OUT: A1.8 (D5), R11.2
GND: A1.4 (GND), A1.29 (GND), C1.2, C3.2, C4.2, C7.2, C8.2, C9.2, C10.2, C11.2, C12.2, C13.2, C14.2, C15.2, C16.2, C18.2, C19.2, C20.2, C21.2, C22.2, C23.2, C24.2, C26.2, C27.2, C28.2, C29.2, C30.2, C31.2, C32.2, C34.2, C35.2, C36.2, C37.2, C38.2, C39.2, C40.2, C42.2, C43.2, C44.2, C45.2, C46.2, C47.2, C48.2, C50.2, C51.2, C52.2, C53.2, C54.2, C55.2, C56.2, C58.2, C59.2, C60.2, C61.2, C62.2, C63.2, C64.2, C66.2, C67.2, C68.2, C69.2, C70.2, C71.2, C72.2, C74.2, C75.2, C76.2, C77.2, C78.2, C79.2, C81.2, C83.2, D1.1 (K), D2.1 (K), D3.1 (K), D4.1 (K), D5.2 (A), D6.2 (A), D8.1 (K), D10.1 (K), D12.1 (K), D14.1 (K), D16.1 (K), D18.1 (K), D20.1 (K), D22.1 (K), J1.2, J1.4, J1.6, J2.2, J2.4, J2.6, J3.2, J4.3, J4.5, J5.3, J5.5, J7.1, J7.4, J7.6, J8.1, J8.4, J8.6, J10.2, J11.2, J12.4, J12.6, J13.3, J14.2, J14.4, J14.6, J15.3, J15.5, J16.2, J18.1, J18.2, Q1.3 (S), R8.1, R12.2, R13.2, R14.2, R15.2, R18.2, R22.2, R24.1, R26.2, R27.1, R29.2, R31.2, R32.1, R34.2, R36.1, R37.2, R39.1, R40.2, R42.1, R43.2, R45.1, R46.2, R67.1, R72.1, R77.1, U1.2 (GND), U2.11 (GND), U2.15 (PPAD), U3.11 (GND), U3.15 (PPAD), U4.4 (V-), U5.3 (GND), U6.3 (GND), U7.3 (GND), U8.3 (GND), U9.3 (GND), U10.3 (GND), U11.1 (PGND), U11.9 (AGND), U12.1 (PGND), U12.9 (AGND), U13.1 (PGND), U13.9 (AGND), U14.1 (PGND), U14.9 (AGND), U15.1 (PGND), U15.9 (AGND), U16.1 (PGND), U16.9 (AGND), U17.1 (PGND), U17.9 (AGND), U18.1 (PGND), U18.9 (AGND), U19.2 (GND), U20.2 (GND), U21.2 (GND), U22.2 (GND), U23.2 (GND), U24.2 (GND), locked.2, locked.3
GPIO1: A1.14 (D11), J15.6
GPIO2: A1.15 (D12), J17.1
GPIO3: A1.16 (D13), J17.2
GPIO4: A1.26 (A7), J17.3
GPIO5: A1.9 (D6), J17.4
GPIO6: A1.10 (D7), J17.5
LED1_CONTROL: J19.3, U19.3 (VSET)
LED1_CURR: A1.20 (A1), R67.2, U20.3 (OUT)
LED1_OUT+: J19.1, R65.1, R66.2
LED1_OUT-: J19.2, L9.2
LED2_CONTROL: J19.6, U21.3 (VSET)
LED2_CURR: A1.21 (A2), R72.2, U22.3 (OUT)
LED2_OUT+: J19.4, R70.1, R71.2
LED2_OUT-: J19.5, L10.2
LED3_CONTROL: J20.3, U23.3 (VSET)
LED3_CURR: A1.22 (A3), R77.2, U24.3 (OUT)
LED3_OUT+: J20.1, R75.1, R76.2
LED3_OUT-: J20.2, L11.2
LED_STATUS: A1.11 (D8), R5.2
LED_WARNING: A1.12 (D9), R4.2
unnamed: A1.23 (A4), J9.1
unnamed: A1.24 (A5), J9.2
unnamed: D1.2 (A), R4.1
unnamed: D2.2 (A), R5.1
unnamed: D3.2 (A), R6.1
unnamed: D4.2 (A), R7.1
unnamed: D7.1 (K), R47.1, R48.1
unnamed: D9.1 (K), R49.1, R50.1
unnamed: D11.1 (K), R51.1, R52.1
unnamed: D13.1 (K), R53.1, R54.1
unnamed: D15.1 (K), R55.1, R56.1
unnamed: D17.1 (K), R57.1, R58.1
unnamed: D19.1 (K), R59.1, R60.1
unnamed: D21.1 (K), R61.1, R62.1
unnamed: D23.2 (A), L9.1, U19.1 (LX)
unnamed: D24.2 (A), L10.1, U21.1 (LX)
unnamed: D25.2 (A), L11.1, U23.1 (LX)
unnamed: J15.2, R9.1
unnamed: J15.4, R10.1
unnamed: J17.6, R11.1
unnamed: C80.2, JP1.1 (A), JP2.1 (A), R65.2, U19.4 (ISENSE), U20.4 (Vs+)
unnamed: JP1.2 (B), R63.2
unnamed: JP2.2 (B), R64.2
unnamed: C82.2, JP3.1 (A), JP4.1 (A), R70.2, U21.4 (ISENSE), U22.4 (Vs+)
unnamed: JP3.2 (B), R68.2
unnamed: JP4.2 (B), R69.2
unnamed: C84.2, JP5.1 (A), JP6.1 (A), R75.2, U23.4 (ISENSE), U24.4 (Vs+)
unnamed: JP5.2 (B), R73.2
unnamed: JP6.2 (B), R74.2
unnamed: Q1.1 (G), R16.1
unnamed: R17.2, locked.1
unnamed: R37.1, RV2.2
unnamed: R40.1, RV3.2
unnamed: R43.1, RV4.2
unnamed: R46.1, RV5.2
unnamed: C2.2, R1.2, SW1.2 (B), U1.4 (Vs+)
unnamed: C2.1, R2.1, U1.5 (Vs-)
unnamed: C5.2, U2.5 (BOOT)
unnamed: C7.1, U2.2 (DELAY_ADJ)
unnamed: R12.1, U2.1 (DUTY_ADJ)
unnamed: R14.1, U2.3 (OSC_ADJ)
unnamed: C6.2, U3.5 (BOOT)
unnamed: C8.1, U3.2 (DELAY_ADJ)
unnamed: R13.1, U3.1 (DUTY_ADJ)
unnamed: R15.1, U3.3 (OSC_ADJ)
unnamed: R21.2, U4.2 (-)
unnamed: R19.2, R20.2, R22.1, U4.6 (-)
unnamed: C17.2, U11.7 (BOOT)
unnamed: C17.1, L1.1, U11.8 (SW)
unnamed: C22.1, U11.6 (VCC)
unnamed: C25.2, U12.7 (BOOT)
unnamed: C25.1, L2.1, U12.8 (SW)
unnamed: C30.1, U12.6 (VCC)
unnamed: C33.2, U13.7 (BOOT)
unnamed: C33.1, L3.1, U13.8 (SW)
unnamed: C38.1, U13.6 (VCC)
unnamed: C41.2, U14.7 (BOOT)
unnamed: C41.1, L4.1, U14.8 (SW)
unnamed: C46.1, U14.6 (VCC)
unnamed: C49.2, U15.7 (BOOT)
unnamed: C49.1, L5.1, U15.8 (SW)
unnamed: C54.1, U15.6 (VCC)
unnamed: C57.2, U16.7 (BOOT)
unnamed: C57.1, L6.1, U16.8 (SW)
unnamed: C62.1, U16.6 (VCC)
unnamed: C65.2, U17.7 (BOOT)
unnamed: C65.1, L7.1, U17.8 (SW)
unnamed: C70.1, U17.6 (VCC)
unnamed: C73.2, U18.7 (BOOT)
unnamed: C73.1, L8.1, U18.8 (SW)
unnamed: C78.1, U18.6 (VCC)
unnamed: C80.1, R66.1, U20.5 (Vs-)
unnamed: C82.1, R71.1, U22.5 (Vs-)
unnamed: C84.1, R76.1, U24.5 (Vs-)
OVERHEAT: A1.13 (D10), R10.2
PELTIER_CONTROL: A1.6 (D3), R7.2, R16.2, R18.1
PELTIER_OUT: J6.2, Q1.2 (D)
PS_1: A1.18 (AREF), A1.27 (+5V), C1.1, C9.1, C10.1, C11.1, C12.1, C13.1, C14.1, C74.1, C75.1, C76.1, C77.1, D7.2 (A), D9.2 (A), D11.2 (A), D13.2 (A), D15.2 (A), D17.2 (A), D19.2 (A), D21.2 (A), J12.1, J13.1, J15.1, L8.2, R3.1, R20.1, R33.1, R47.2, R49.2, R51.2, R53.2, R55.2, R57.2, R59.2, R61.2, U4.8 (V+), U5.5 (VCC), U6.5 (VCC), U7.5 (VCC), U8.5 (VCC), U9.5 (VCC), U10.5 (VCC)
PS_2: J12.2, R17.1, U4.3 (+)
PS_RAW_OUT: J12.5, R21.1, U4.1, U4.5 (+)
PS_TRIGGER: J12.3, R6.2, R19.1, U4.7
RAIL1+: C18.1, C19.1, C20.1, C21.1, J2.1, J2.3, J2.5, L1.2, R25.1
RAIL1_EN: J5.1, R27.2, U5.2
RAIL1_PG: D8.2 (A), R48.2, U11.4 (PG)
RAIL2+: C26.1, C27.1, C28.1, C29.1, J7.3, J7.5, J10.1, L2.2, R30.1
RAIL2_EN: J10.3, R32.2, U6.2
RAIL2_PG: D10.2 (A), R50.2, U12.4 (PG)
RAIL3+: C34.1, C35.1, C36.1, C37.1, J5.2, J5.4, J5.6, L3.2, R35.1
RAIL3_EN: J8.2, R36.2, U7.2
RAIL3_PG: D12.2 (A), R52.2, U13.4 (PG)
RAIL4+: C42.1, C43.1, C44.1, C45.1, J4.2, J4.4, J4.6, L4.2, R38.1
RAIL4_EN: J7.2, R39.2, U8.2
RAIL4_PG: D14.2 (A), R54.2, U14.4 (PG)
RAIL5+: C50.1, C51.1, C52.1, C53.1, J8.3, J8.5, J11.1, L5.2, R41.1
RAIL5_EN: J11.3, R42.2, U9.2
RAIL5_PG: D16.2 (A), R56.2, U15.4 (PG)
RAIL6+: C58.1, C59.1, C60.1, C61.1, J1.1, J1.3, J1.5, L6.2, R44.1
RAIL6_EN: J4.1, R45.2, U10.2
RAIL6_PG: D18.2 (A), R58.2, U16.4 (PG)
TEMP_SENSOR: A1.5 (D2), J13.2, R3.2
VALVE1_IN: J14.1, U2.14 (INPUT)
VALVE1_OUT: C5.1, D5.1 (K), J14.3, U2.6 (OUT1), U2.7 (OUT2)
VALVE2_IN: J14.5, U3.14 (INPUT)
VALVE2_OUT: C6.1, D6.1 (K), J16.1, U3.6 (OUT1), U3.7 (OUT2)
VALVE_12V: C3.1, C4.1, C66.1, C67.1, C68.1, C69.1, L7.2, R28.1, U2.8 (VPS1), U2.9 (VPS2), U2.10 (+VS), U3.8 (VPS1), U3.9 (VPS2), U3.10 (+VS)
VALVE_PG: D20.2 (A), R60.2, U17.4 (PG)

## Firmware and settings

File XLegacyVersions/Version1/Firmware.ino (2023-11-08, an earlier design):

#include <OneWire.h>
#include <DallasTemperature.h>
#include <PID_v1.h>

#define TARGET_TEMP_C 21

// Pin definitions
#define ONE_WIRE_BUS 2
#define PELTIER_OUT_PIN 3
#define FLIPPER_ENABLE_PIN 4
#define FLIPPER_OUT_PIN 5
#define LED_STATUS_PIN 8
#define LED_WARNING_PIN 9

#define CAM_SYNC_PIN 11
#define MIC_SYNC_PIN 12

// Setup a oneWire instance to communicate with temperature sensor
OneWire oneWire(ONE_WIRE_BUS);  
DallasTemperature sensors(&oneWire);

// PID variables for Peltier
double TargetTemp, CurrTemp, PeltierPWM;

unsigned long myTime;

volatile bool syncTrigger;
volatile int syncCount;
volatile bool syncLive;

volatile int flipperState;
volatile int flipperForceCount;
volatile int flipperPrev;


// PID parameters for Peltier (P = 5, I = 5, D = 1 as a guess)
PID myPID(&CurrTemp, &PeltierPWM, &TargetTemp,5,5,1, REVERSE);

void setup(void)
{
  sensors.begin();  // Start up the library
  Serial.begin(9600);
  sensors.requestTemperatures();
  TargetTemp = TARGET_TEMP_C;
  CurrTemp = sensors.getTempCByIndex(0);
  myPID.SetMode(AUTOMATIC);
  myPID.SetSampleTime(2000);
  
  pinMode(PELTIER_OUT_PIN, OUTPUT);
  pinMode(FLIPPER_ENABLE_PIN, INPUT);
  pinMode(FLIPPER_OUT_PIN, OUTPUT);
  pinMode(LED_STATUS_PIN, OUTPUT);
  pinMode(LED_WARNING_PIN, OUTPUT);
  pinMode(CAM_SYNC_PIN, OUTPUT);
  pinMode(MIC_SYNC_PIN, OUTPUT);

  digitalWrite(FLIPPER_OUT_PIN, LOW);
  digitalWrite(LED_STATUS_PIN, LOW);
  digitalWrite(LED_WARNING_PIN, LOW);
  digitalWrite(MIC_SYNC_PIN, LOW);
  digitalWrite(CAM_SYNC_PIN, HIGH);

  syncTrigger = 0;
  syncCount = 0;
  syncLive = 1;
  flipperForceCount = 0;
  flipperPrev = 0;

  cli();//stop interrupts

//set timer1 interrupt at 10Hz for flipper
  TCCR1A = 0;// set entire TCCR1A register to 0
  TCCR1B = 0;// same for TCCR1B
  TCNT1  = 0;//initialize counter value to 0
  // set compare match register for 1hz increments
  OCR1A = 1550;// = (16*10^6) / (10*1024) - 1
  // turn on CTC mode
  TCCR1B |= (1 << WGM12);
  // Set CS10 and CS12 bits for 1024 prescaler
  TCCR1B |= (1 << CS12) | (1 << CS10);  
  // enable timer compare interrupt
  TIMSK1 |= (1 << OCIE1A);

sei();//allow interrupts

}

ISR(TIMER1_COMPA_vect){ // flipper code, runs at 10Hz

    if(digitalRead(FLIPPER_ENABLE_PIN)){
      flipperState = random(0,2);
      if (flipperForceCount > 9 && flipperState==flipperPrev){
        flipperState = (flipperState-1)*-1;
      }
      if (flipperState == flipperPrev){
        flipperForceCount = flipperForceCount + 1;
        }

      if (flipperState != flipperPrev){
        flipperPrev = flipperState;
        flipperForceCount = 0;
      }

      digitalWrite(FLIPPER_OUT_PIN, flipperState);
      digitalWrite(LED_STATUS_PIN, flipperState);
    }  
   else{
    digitalWrite(FLIPPER_OUT_PIN,LOW);
    digitalWrite(LED_STATUS_PIN, LOW);
    }


 if(syncTrigger != digitalRead(FLIPPER_ENABLE_PIN)){
    Serial.println("Detected Trigger");
    syncTrigger = digitalRead(FLIPPER_ENABLE_PIN);
    digitalWrite(MIC_SYNC_PIN, HIGH);
    digitalWrite(CAM_SYNC_PIN, LOW);
    syncCount = 0;
    syncLive = 1;
 }
  if(syncCount >= 2){
   digitalWrite(MIC_SYNC_PIN, LOW);
   digitalWrite(CAM_SYNC_PIN, HIGH);
   syncLive = 0;
   syncCount = 0;
  } 
    
 if (syncLive == 1){
   syncCount = syncCount+1;
    }

}

void loop(void) // update Peltier PWM value and serial print every 2s
{ 
//  Serial.print("Rail 5 voltage: ");
//  Serial.print(analogRead(4)*0.03086392334);
//  Serial.println("V");
//  Serial.print("Rail 6 voltage: ");
//  Serial.print(analogRead(5)*0.03086392334);
//  Serial.println("V");

  sensors.requestTemperatures();

  //print the temperature in Celsius
  Serial.print("Temperature: ");
  Serial.print(sensors.getTempCByIndex(0));
  Serial.println("C");

  //update Peltier status
  
  CurrTemp = sensors.getTempCByIndex(0);
  myPID.Compute();
  
  analogWrite(PELTIER_OUT_PIN,PeltierPWM);
  Serial.print("PWM output: ");
  Serial.println(PeltierPWM);

  delay(2000);
}

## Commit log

2023-11-08 File renaming
    [Case_Base.ipt, Case_Base.stl, Case_Lid.ipt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]
2024-02-18 Added v2 and v3 PCB design files
    [ExtraComponents.csv, al8861.kicad_sch, bom.csv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]
2024-04-26 Update for case
    [Case_Base.ipt, Case_Base.stl, Case_Lid.ipt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]
2024-04-26 Case > Enclosure
    [Enclosure_Base.ipt, Enclosure_Base.stl, Enclosure_Lid.ipt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]

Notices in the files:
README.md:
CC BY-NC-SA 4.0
